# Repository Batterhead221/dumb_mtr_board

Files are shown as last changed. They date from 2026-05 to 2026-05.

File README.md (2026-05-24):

# DUMB_MTR_BOARD

<p align="center">
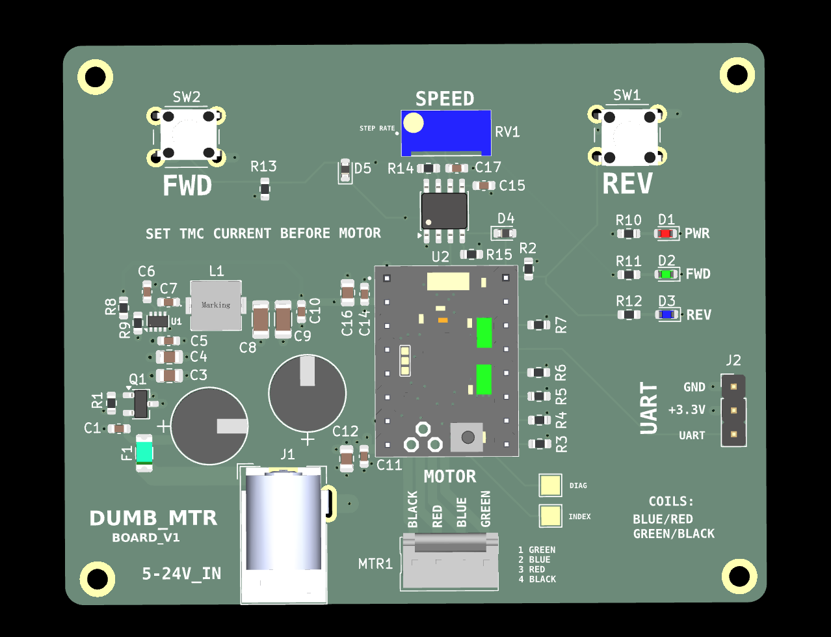
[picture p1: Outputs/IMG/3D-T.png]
DUMB_MTR_BOARD top 3D board render
  
</p>

<p align="center">
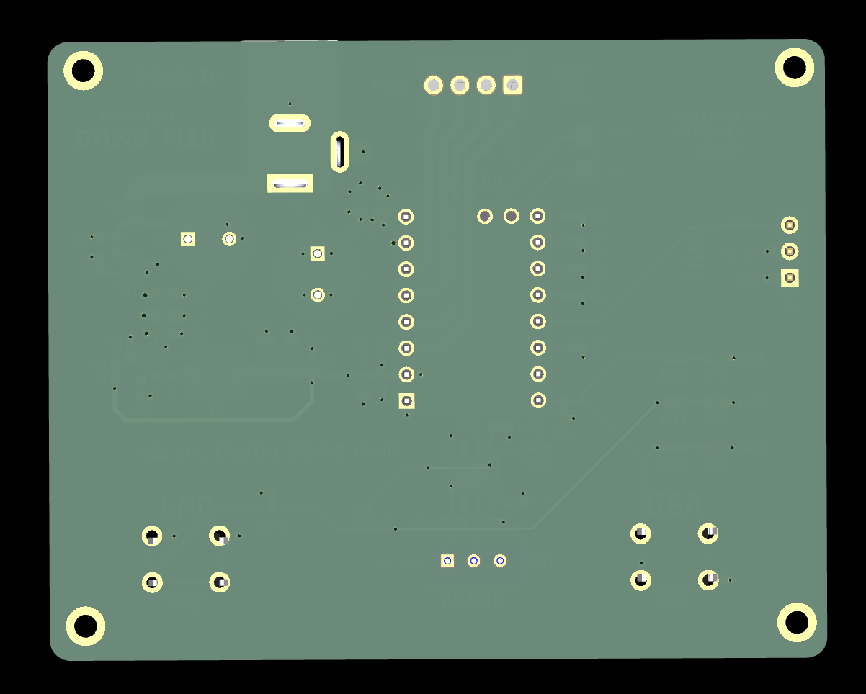
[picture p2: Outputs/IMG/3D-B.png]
DUMB_MTR_BOARD bottom 3D board render
  
</p>

Standalone stepper motor controller board with local forward/reverse jog buttons, speed adjustment, status LEDs, and a TMC stepper driver module.

Motor controller board

DUMB_MTR Board provides a small standalone interface for driving a stepper motor.

Core functions:

* Power input from 5-24V
* Stepper motor output connector
* Forward and reverse jog buttons
* Speed adjustment potentiometer
* RGB/status LEDs
* UART header for driver configuration/debugging
* Manual local control without needing the Brain_Board

Input power:     5-24V
Motor driver:    TMC stepper driver module
Controls:        FWD / REV buttons
Adjustment:      Speed potentiometer
Indicators:      Power / direction LEDs
Motor output:    4-pin stepper connector
Logic rail:      On-board 3.3V regulator

# DUMB_MTR Board

A compact standalone stepper motor control board built around a TMC stepper driver module.

This board is designed as a simple hands-on motor controller with local direction controls, speed adjustment, motor output, status LEDs, and a selectable input power source.

## System Role

```text
5-24V input power
        ↓
DUMB_MTR_BOARD
        ↓ local FWD / REV buttons + speed potentiometer
TMC stepper driver module
        ↓
4-wire stepper motor
```

DUMB_MTR_BOARD is the controller and driver carrier for a simple local stepper motor setup.

## Key Specs

| Item | Value |
|---|---|
| Board role | Standalone stepper motor controller |
| Input power | 5-24V |
| Motor driver | TMC stepper driver module |
| Motor output | 4-pin stepper connector |
| Local controls | Forward / reverse jog buttons |
| Adjustment | Speed potentiometer |
| Indicators | Power / direction / status LEDs |
| Debug/config | UART header |
| Logic rail | On-board 3.3V regulator |
| Main use | Manual motor control and driver testing |

## Main Features

- 5-24V input power
- TMC stepper driver module footprint/header
- 4-pin stepper motor output connector
- Forward jog button
- Reverse jog button
- Speed adjustment potentiometer
- RGB/status LED indicators
- UART header for driver configuration/debugging
- On-board 3.3V logic regulation
- Manual local motor control without BRAIN_BOARD
- Compact bench-testable layout

## Controls

### Forward / Reverse Jog

The board includes local direction/jog buttons for manual control.

```text
FWD button → forward jog command
REV button → reverse jog command
```

### Speed Potentiometer

The speed potentiometer provides a local analog adjustment for motor speed or step timing.

```text
Potentiometer → speed / rate control input
```

Firmware or local control logic should map the potentiometer reading into an appropriate step rate.

## Motor Driver

The board is built around a TMC stepper driver module.

Typical driver-side signals may include:

| Signal | Purpose |
|---|---|
| STEP | Step pulse input |
| DIR | Direction input |
| EN | Driver enable |
| UART | Driver configuration/debugging |
| VM | Motor supply input |
| GND | Shared ground |
| A1/A2/B1/B2 | Stepper coil outputs |

Confirm the exact TMC module pinout before installing a driver module.

## Power Architecture

```text
5-24V input
    ↓
motor-driver VM rail
    ↓
TMC stepper driver module
    ↓
motor phase outputs
```

Logic power is generated locally:

```text
input power → 3.3V regulator → local logic/control rail
```

## Motor Output

The motor output is a 4-pin connector for a bipolar stepper motor.

Typical coil mapping:

```text
Coil A → A1 / A2
Coil B → B1 / B2
```

Always verify motor coil pairs with a meter before connecting the motor.

## UART Header

The UART header is intended for TMC driver configuration, tuning, or debug access.

```text
UART TX/RX
GND
logic reference
```

Match voltage levels before connecting any external USB-to-UART adapter.

## Design Notes

- Keep motor-current paths short and wide.
- Keep motor VM routing away from low-level control signals where practical.
- Verify the TMC driver module orientation before power-up.
- Confirm the potentiometer direction and firmware mapping during bring-up.
- Start with current-limited input power during first tests.
- Do not hot-plug the stepper motor while the driver is powered.
- Keep UART/debug access available for driver tuning.

## Bring-Up Checklist

1. Inspect soldering and connector orientation.
2. Confirm no short between input power and GND.
3. Confirm no short between 3.3V and GND.
4. Power the board with a current-limited supply.
5. Verify the 3.3V rail.
6. Confirm power/status LEDs behave as expected.
7. Verify the TMC driver module orientation.
8. Connect UART/debug if driver configuration is needed.
9. Confirm FWD and REV buttons are read correctly.
10. Confirm the speed potentiometer changes the command rate.
11. Connect the motor after verifying coil pairs.
12. Start with low current and slow speed before full operation.

## Repository Output Images

Expected image paths for GitHub README rendering:

```text
Outputs/
  IMG/
    3D-T.png
    3D-B.png
    SCHEMATIC.png
    L1-SIG.png
    L2-GND.png
```

## Safety / Design Note

DUMB_MTR_BOARD handles motor power. Verify input polarity, motor wiring, driver orientation, current settings, and thermal behavior before running the motor under load.

Designed & engineered by Brandon Shelly

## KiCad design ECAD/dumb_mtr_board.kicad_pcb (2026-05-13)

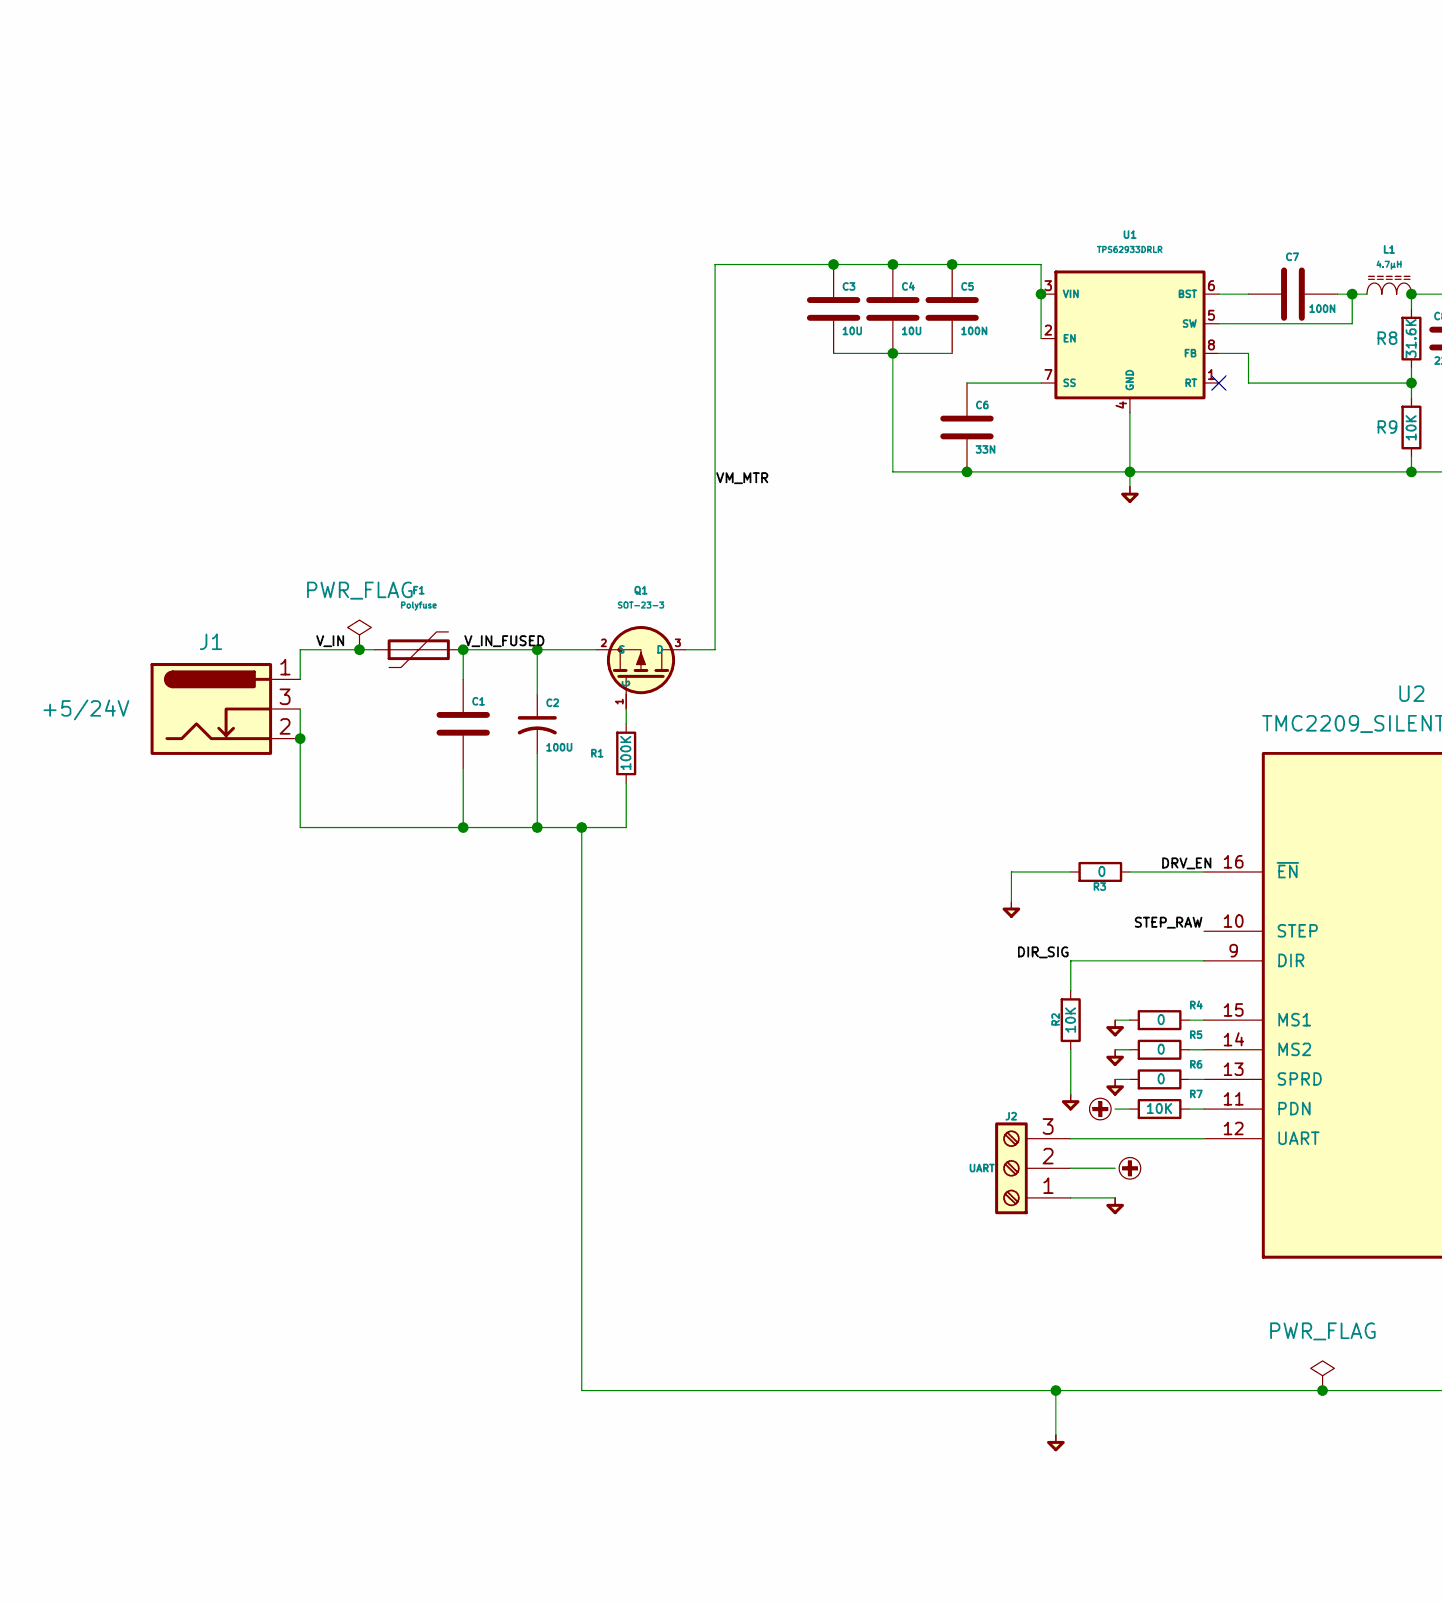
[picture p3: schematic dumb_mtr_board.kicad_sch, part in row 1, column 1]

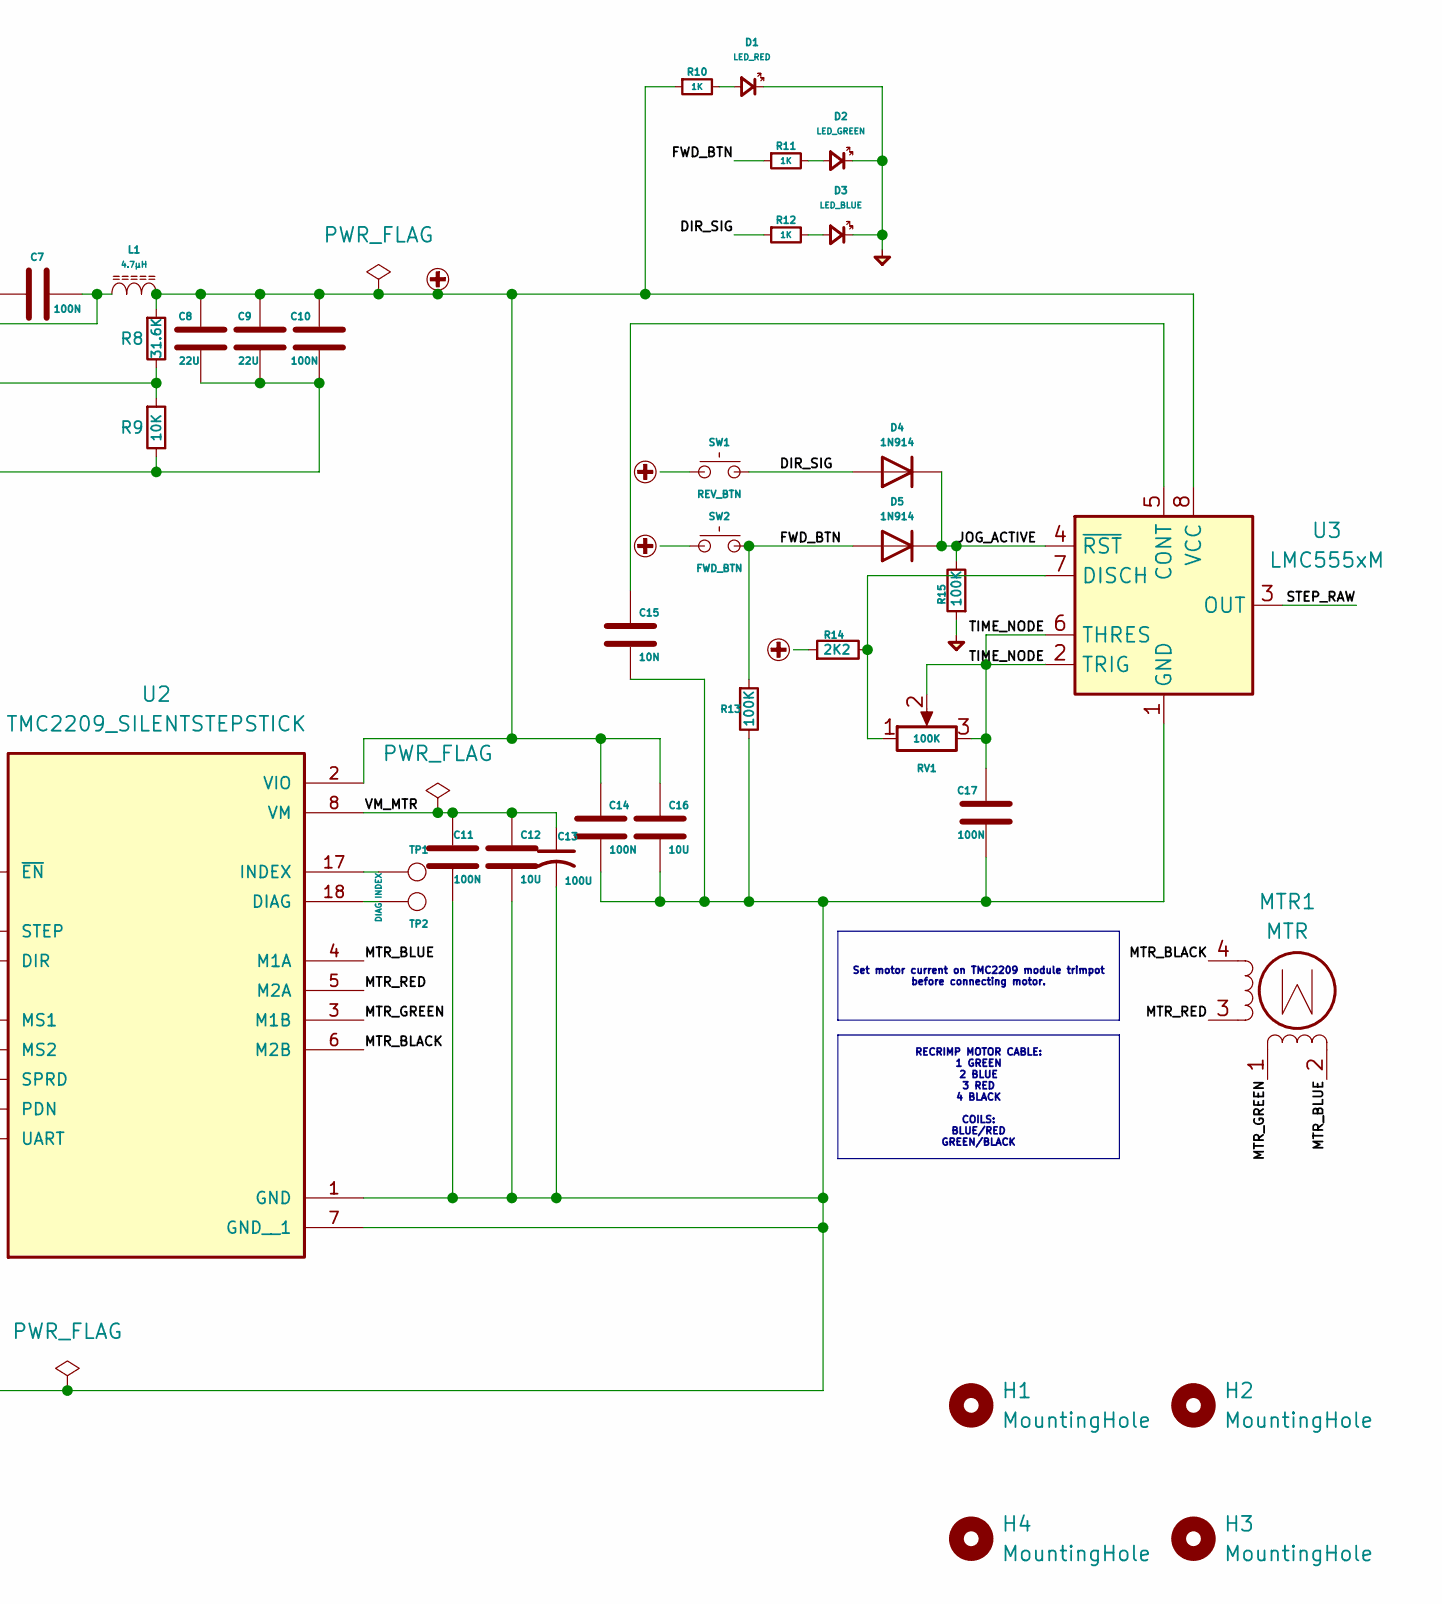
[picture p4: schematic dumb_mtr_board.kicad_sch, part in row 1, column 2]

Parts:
C1, C5, C7, C10, C11, C14, C17: 100N; C_0603_1608Metric
C2, C13: 100U; PCAP_8x11_5-THRU-ELECT_NCA
C3, C4, C12, C16: 10U; C_0805_2012Metric
C6: 33N; C_0603_1608Metric
C8, C9: 22U; C_1206_3216Metric
C15: 10N; C_0603_1608Metric
D1: LED_RED; LED_0603_1608Metric
D2: LED_GREEN; LED_0603_1608Metric
D3: LED_BLUE; LED_0603_1608Metric
D4, D5: 1N914; D_0603_1608Metric
F1: Polyfuse; Fuse_1206_3216Metric
H1, H2, H3, H4: MountingHole; MountingHole_2.2mm_M2_ISO14580_Pad_TopBottom
J1: +5/24V; BarrelJack_Wuerth_6941xx301002
J2: UART; PinHeader_1x03_P2.54mm_Vertical
L1: 4.7µH; L_SRP5030TA4R7M
MTR1: MTR; MTA-4
Q1: SOT-23-3; TSOT-23
R1, R13, R15: 100K; R_0603_1608Metric
R2, R7, R9: 10K; R_0603_1608Metric
R3, R4, R5, R6: 0; R_0603_1608Metric
R8: 31.6K; R_0603_1608Metric
R10, R11, R12: 1K; R_0603_1608Metric
R14: 2K2; R_0603_1608Metric
RV1: 100K; TRIM_3296W-1-104LF
SW1: REV_BTN; SW_PUSH_6mm
SW2: FWD_BTN; SW_PUSH_6mm
TP1: INDEX; TestPoint_Pad_2.0x2.0mm
TP2: DIAG; TestPoint_Pad_2.0x2.0mm
U1: TPS62933DRLR; SOT-583-8
U2: TMC2209_SILENTSTEPSTICK; MODULE_TMC2209_SILENTSTEPSTICK; PARTREV 1.20
U3: LMC555xM; SOIC-8_3.9x4.9mm_P1.27mm

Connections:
+3.3V: C8.2, C9.2, C10.2, C14.2, C16.1, J2.2, L1.2, R7.1, R8.1, R10.1, R14.1, SW1.1, SW2.1, U2.2 (VIO), U3.8 (VCC)
/DIR_SIG: D4.2 (A), R2.1, R12.1, SW1.2, U2.9 (DIR)
/DRV_EN: R3.2, U2.16 (~EN)
/FWD_BTN: D5.2 (A), R11.1, R13.1, SW2.2
/JOG_ACTIVE: D4.1 (K), D5.1 (K), R15.2, U3.4 (~RST)
/MTR_BLACK: MTR1.4, U2.6 (M2B)
/MTR_BLUE: MTR1.2 (-_2), U2.4 (M1A)
/MTR_GREEN: MTR1.1, U2.3 (M1B)
/MTR_RED: MTR1.3, U2.5 (M2A)
/STEP_RAW: U2.10 (STEP), U3.3 (OUT)
/TIME_NODE: C17.2, RV1.2, RV1.3, U3.2 (TRIG), U3.6 (THRES)
/VM_MTR: C3.1, C4.1, C5.1, C11.2, C12.1, C13.1, Q1.3 (D), U1.2 (EN), U1.3 (VIN), U2.8 (VM)
/V_IN: F1.1, J1.1
/V_IN_FUSED: C1.1, C2.1, F1.2, Q1.2 (S)
GND: C1.2, C2.2, C3.2, C4.2, C5.2, C6.2, C8.1, C9.1, C10.1, C11.1, C12.2, C13.2, C14.1, C15.2, C16.2, C17.1, D1.1 (K), D2.1 (K), D3.1 (K), J1.2, J1.3, J2.1, R1.2, R2.2, R3.1, R4.1, R5.1, R6.1, R9.2, R13.2, R15.1, U1.4 (GND), U2.1 (GND), U2.7 (GND__1), U3.1 (GND)
unnamed: D1.2 (A), R10.2
unnamed: D2.2 (A), R11.2
unnamed: D3.2 (A), R12.2
unnamed: J2.3, U2.12 (UART)
unnamed: Q1.1 (G), R1.1
unnamed: C7.1, U1.6 (BST)
unnamed: R8.2, R9.1, U1.8 (FB)
unnamed: C6.1, U1.7 (SS)
unnamed: C7.2, L1.1, U1.5 (SW)
unnamed: TP2.1 (1_1), U2.18 (DIAG)
unnamed: TP1.1 (1_1), U2.17 (INDEX)
unnamed: R4.2, U2.15 (MS1)
unnamed: R5.2, U2.14 (MS2)
unnamed: R7.2, U2.11 (PDN)
unnamed: R6.2, U2.13 (SPRD)
unnamed: C15.1, U3.5 (CONT)
unnamed: R14.2, RV1.1, U3.7 (DISCH)

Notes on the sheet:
Set motor current on TMC2209 module trimpot before connecting motor.
RECRIMP MOTOR CABLE: 1 GREEN 2 BLUE 3 RED 4 BLACK COILS: BLUE/RED GREEN/BLACK

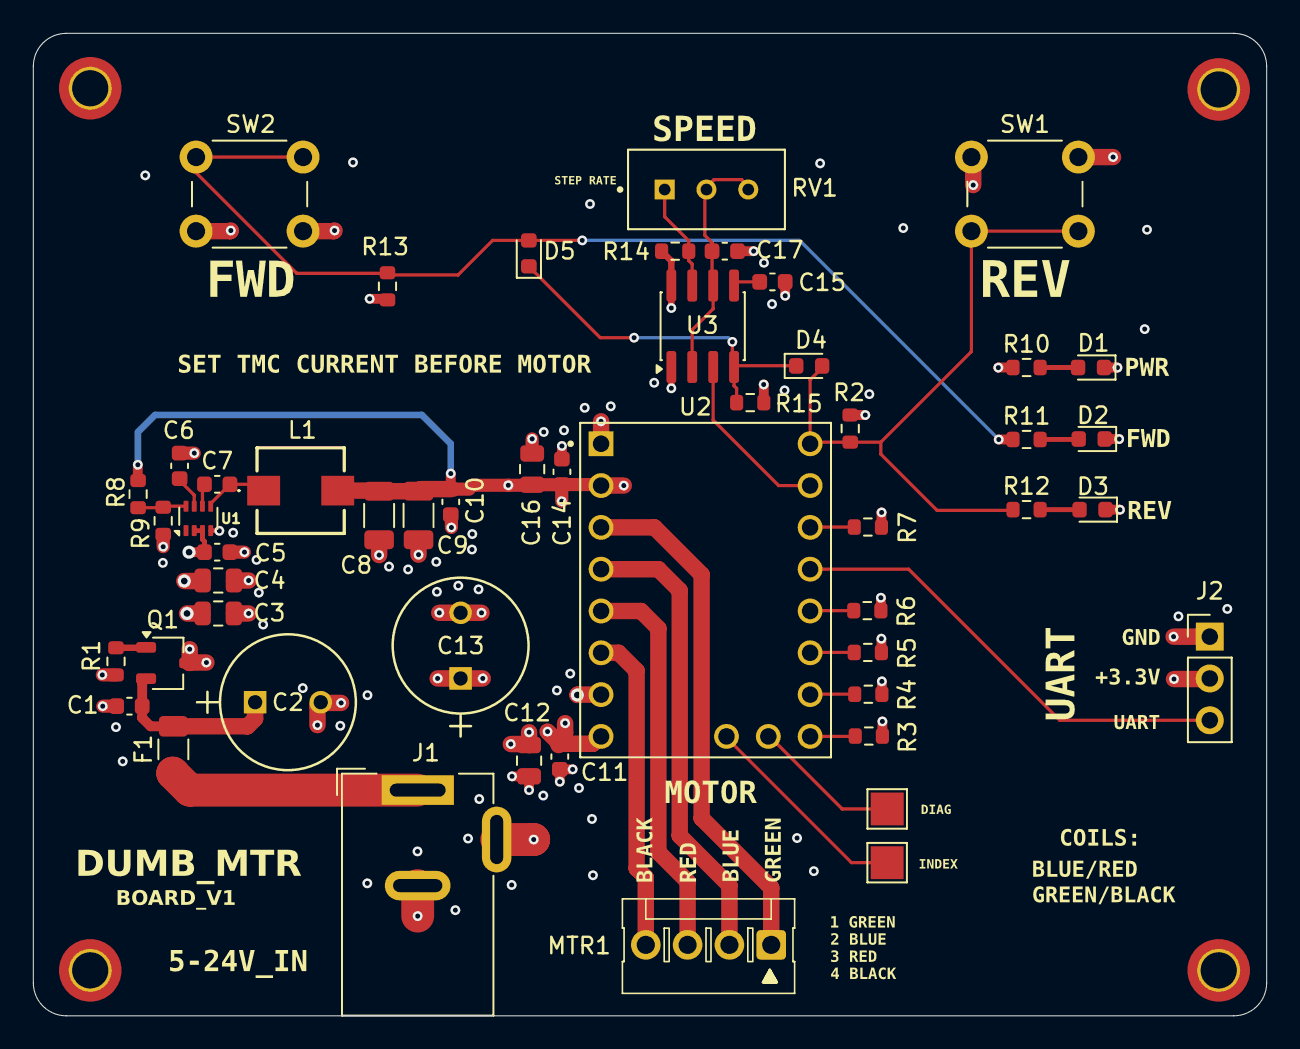
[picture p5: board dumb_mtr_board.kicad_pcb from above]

Board: 4 copper layers, 74.9 x 59.7 mm, 55 parts (0 on the bottom side), 32 nets.

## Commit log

2026-05-06 new repo
    [dumb_mtr_board.kicad_pcb, dumb_mtr_board.kicad_sch]
2026-05-13 Revised repo
    [dumb_mtr_board.kicad_pcb, dumb_mtr_board.kicad_sch]
2026-05-13 Added stitching vias
    [dumb_mtr_board.kicad_pcb]
2026-05-14 switched connectors
